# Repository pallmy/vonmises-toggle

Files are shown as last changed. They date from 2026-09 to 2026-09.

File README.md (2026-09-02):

# Von Mises toggle — CAD toolchain

Parametric model, analysis, and one-command fabrication for the
bistable over-center toggle experiment. Everything derives from three
sketch numbers — `b` (frame leg P–S), `R` (arm P–T), `gamma1`
(state-1 interior angle) — plus `scale` (mm per sketch unit) and
`phi` (anchor direction). ~1850 lines across 10 source files.

## Quick start

    ./kit --preview            # look at the configuration, then stop
    ./kit                      # generate the fabrication kit -> fab/
    open config_designer.html  # slider version of --preview

(`kit` is the venv wrapper in the Mac working copy; in the repo run
`python make_kit.py` with build123d/trimesh/ezdxf/shapely installed.)

## The model (one triangle)

P = pivot, S = band anchor (fixed at distance b, direction phi),
T = arm tip on a circle of radius R. One degree of freedom: gamma.

    span    c(g) = sqrt(b^2 + R^2 - 2 b R cos g)     law of cosines
    energy  E(g) = 1/2 k (c - L0)^2  for c > L0, else 0 (band slack)
    torque  tau(g) = k (c - L0) * b R sin g / c      = dE/dg

Dead center at g = 180 (max stretch, zero moment arm). The REAL
resting states are hardware stops, not the energy symmetry:
- default geometry (b .8803, R 1.7178, phi 127.58): measured
  state 1 = 104.0, state 2 = 233.0 (plate corner)
- current experimental geometry (b .875, R 2.53, phi 150,
  gamma1 135): measured state 1 = 134.9; the mirror 225 is
  UNREACHABLE — plate corner stop lands at 287.4. Decision open:
  engineered second stop vs accept vs retune phi.

Design rules measured from the original frame: ONE standoff radius
w = 7.532 mm for every frame edge, corner arc, and fillet around P
and S; the clevis stop faces are calibrated to it. Stop-face
compensation: flush angle = gamma1 + 1.4 (the 0.25 mm running
clearance costs ~1.4 deg of over-travel).

## Fabrication pipeline

    config_designer.html   sliders -> the kit command
            |
        make_kit.py        orchestrator: resolves params, writes fab/
            +-- generate_frame.py    frame planform -> fab/laser/*.dxf
            |     make_kit READS THE DXF BACK (detect_datums) and
            |     re-measures b/phi from it: the file is the truth
            +-- clevis_generator.py  clevis + pin -> fab/print/*.stl
            |                        (+ STEP into fab/cad/)
            +-- toggle_assembly.py   posed states -> fab/cad/*.step

## File-by-file (current state)

### make_kit.py (264) — the conductor
Inputs are the sketch geometry (b, R, gamma1; gamma2 None = mirrored),
hardware knobs (pin-d, clearances, blade-t, rod-od), plumbing
(frame-mode, phi, standoff, preview). Fixed clevis body dims are code
constants (the measured joint). Flow: resolve -> frame -> detect
datums -> config preview (--preview exits) -> parts -> assemblies ->
BUILD_SHEET.md -> file listing. Uses socket_depth() so the sheet's
rod length always matches the actual printed socket.

### generate_frame.py (198) — the laser master
build_outline(): 12-vertex planform, clockwise; every arc radius w,
every edge offset w from a datum. Emits exact bulge arcs
(tan(sweep/4)) for the DXF and a discretized loop for shapely.
build_cutouts(): inward offset by margin (12.5), tab clipped solid,
8 mm diagonal rib subtracted, corners rounded by buffer(-f).buffer(f).
Defaults reproduce the original hand-drawn cutout.

### clevis_generator.py (247) — the joint
make_clevis(): body + rounded fork + counterbored Ø3.3 cross bore.
The stop plane (one inclined plane at standoff+clearance from the
bore, direction set by tab_stop_deg) is used twice: channel end wall
(cut) and tab wedge face (add) — the frame edge lands flush at
exactly one rotation. Rod mount is a FEMALE SOCKET by default
(--rod-mount socket): flush-sided boss, Ø rod_od+0.3 bore; the old
ribbed stem survives behind --rod-mount stem. socket_depth() is the
single source of truth for the depth cap (steep stop angles pull the
wall into the boss; e.g. 105.4 deg -> 10.0 mm, 136.4 deg -> 4.7 mm).
make_pin(): flush pin, chamfered tip, torus snap ridge into the far
counterbore. make_arm(): legacy printed arm.

### toggle_assembly.py (223) — DXF in, posed STEP out
detect_datums(): x-order invariant — 4 tab mount holes leftmost,
pivot at max x, the remaining hole is the anchor (survives any phi;
the old neighbor-clustering rule did not). bulge_points()/
polyline_points() discretize DXF arcs; make_frame_from_dxf() extrudes
the true planform, pivot at origin. build_assembly(): one composite
Location per part (translate bore to origin, rotX +90 to put the pin
axis on Z, rotZ so the stem points along phi - gamma); rod seated at
the socket floor. Exports a labeled Compound (separate components in
Fusion/SolidWorks).

### config_designer.html (252) — the eyes
Self-contained slider page (no server): JS mirror of the outline and
triangle math. Drive gamma1 directly or by beta (span-to-horizon,
ray/circle inversion); gamma2 mirrors unless unchecked; corner-angle
arcs at S and T; span, rod-cut readouts; emits the exact kit command.

### toggle_sketch.py (194) — the original 2D solver
--gammas or --horizons (beta -> gamma inversion), derived-dims table,
DXF/PNG sketches, --two-states mirrored layer.

### MATLAB (105 + 120 + 122)
toggle_energy_torque.m: E(g) over tau(g), asymmetric stops marked,
both barriers printed. toggle_paper_figure.m: linkage + energy
two-panel paper figure. toggle_model_sheet.m: beige planform
presentation view. Run: matlab -batch "cd('cad'); <name>"
(R2025b native at ~/Desktop/MATLAN; R2024b needs arch -x86_64).

### generate_truss.py (125) — legacy
First-session symmetric two-bar truss STL sweep. Superseded.

### Data
frame_cutout.dxf (original hand-drawn master, used by
--frame-mode original) · fab/ (regenerable kit incl.
fit_test_plate.stl: clevis pre-rotated fork-up + 4 pins, one-import
print file) · output/ (analysis exports).

## Verification status

- Generated frame overlays the original DXF exactly (outline/holes)
- Collision sweeps: default geometry stops measured 104.0/233.0;
  135-deg geometry state 1 measured 134.9, state 2 = 287.4
  (mirror unreachable), zero mid-travel interference in both
- Print staging: fit-test plate sliced clean, supportless
  (fork-up orientation), ~22 min / ~3.5 g
- NOT yet validated: print-fit clearances on the actual printer;
  k hang test pending (all energies still k = 1 units)

## Open items

- Print + fit-check the kit (pin bore, blade slot, rod socket)
- State-2 decision for the 135-deg geometry (engineered stop /
  accept 287 / retune phi)
- k measurement -> real joules on the analysis and band free length
- Optional: --verify sweep inside make_kit; kit.bat for Windows;
  lattice tip mass (picoGK)

## Installation

    python3 -m venv .venv
    .venv/bin/pip install -r requirements.txt
    .venv/bin/python make_kit.py --preview

Paths in this repository are flat (no cad/ prefix). MATLAB scripts
run on R2024b+ with no toolboxes.

## Results

results/ holds validation artifacts: the generated-vs-original frame
overlay, the energy/torque analysis with measured stop angles, and
configuration previews.

## AI assistance disclosure

The implementation of this toolchain was developed with the
assistance of an AI coding tool (Claude, Anthropic), directed by the
author. All design specifications, physical measurements (frame
datum geometry, reference joint dimensions), experimental design,
and hardware validation are the author's.

## Citation

If you use this toolchain, please cite the repository:
https://github.com/pallmy/vonmises-toggle

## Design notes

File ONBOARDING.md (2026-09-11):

Von Mises toggle rig, repo pointers for Yingchao

Code is in cad/ on branch parametric-geometry-cad. I'll walk you through the purpose and the build in person, this is just a map so you can poke around first.

Start here
- cad/README.md, the file by file walkthrough and current status
- fab/BUILD_SHEET.md, what's on the bench right now (numbers, cut stock, assembly steps)

Source files (cad/)
- config_designer.html, slider page to pick the geometry, no server
- make_kit.py, runs the whole pipeline and writes fab/
- generate_frame.py, the laser frame, writes fab/laser/frame_cutout.dxf
- clevis_generator.py, clevis, pin, rod socket, writes fab/print/*.stl
- toggle_assembly.py, poses the resting states, writes fab/cad/*.step
- wing_generator.py, the wing parts (foam board, cantilever, clamp, end caps)
- toggle_energy_torque.m and the other .m files, the MATLAB analysis

Outputs (cad/fab/)
- laser/ the DXFs
- print/ the STLs and the sliced wing plate
- cad/ the STEP assemblies (open in Fusion or SolidWorks)

Run it
- ./kit --preview to see the config, ./kit to write the kit
- clean checkout: python make_kit.py with build123d, trimesh, ezdxf, shapely installed
- MATLAB is R2025b

Open threads
- k hang test (top priority, everything downstream needs it)
- state 2 stop for the 135 geometry (mirror unreachable)
- print fit check on the real printer

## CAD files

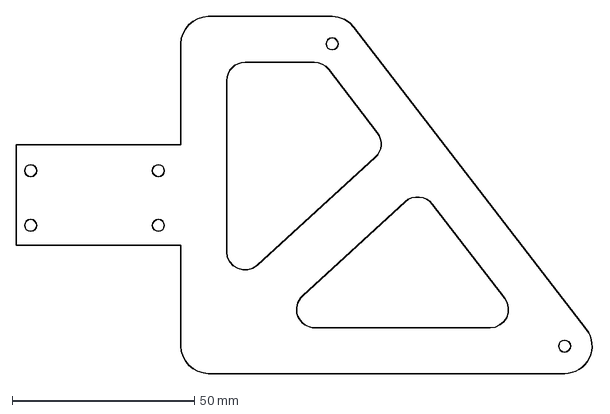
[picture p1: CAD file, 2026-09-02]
frame_cutout.dxf
158.4 x 97.9 mm

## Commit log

2026-09-02 Von Mises toggle: parametric CAD toolchain, analysis, and fab kit
    Model + fabrication pipeline for a bistable over-center toggle:
    frame DXF generator (laser), clevis/pin generator (build123d),
    posed assembly STEP export, collision-calibrated hard stops,
    energy/torque analysis (MATLAB), slider config designer, and a
    one-command kit orchestrator with build sheet.
    [frame_cutout.dxf]
2026-09-11 Add wing subsystem + onboarding notes
    - wing_generator.py: parametric foam-board wing — three carbon spars,
    a printed cantilever that mounts the 5 mm motor hub, a grip clamp,
    and one-piece end caps that hold the spars and carry the four-bolt
    fiberglass-truss mount on the floor slab.
    - generate_frame.py: grow the mounting tab so the truss hole pattern
    fits with margin.
    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
